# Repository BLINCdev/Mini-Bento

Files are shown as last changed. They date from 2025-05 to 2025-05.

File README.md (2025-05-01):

# Mini Bento Arm
The [Mini Bento Arm](https://blincdev.ca/mini-bento/mini-bento-overview/) is a 3D printable robotic arm designed specifically for education and take home rehabilitation applications. Building off the success of the full-scale [Bento Arm](https://github.com/BLINCdev/Bento-Arm-Hardware) (which has been used extensively as a robotic prosthesis for myoelectric training and research), the 1/3 scale Mini Bento Arm provides many of the same features for a fraction of the cost (and space!). The Dynamixel XL330-M288-T actuators are used in the arm to provide up to 4 movements and include joint feedback that can be used for sensory feedback or machine learning. The arm can be controlled through a computer via our brachI/Oplexus software or directly via the onboard OpenRB-150 controller through an Arduino interface. 

## Build your own Mini Bento Arm
The Mini Bento Arm consists of off-the-shelf X-series Dynamixel actuators and brackets, metric fasteners, and custom 3D printed parts. Instructions for building the arm and setting up the actuators can be found in _'Mini Bento Arm - Assembly Guide.doc'_. The assembly guide will be your main goto document while printing and building the arm and includes references to the other files in the repository:

* __Bill of Materials:__ A detailed list of the off-the-shelf materials and parts required to build the Mini Bento Arm. Note: We have listed the distributors that we have used in the past as a point of reference, but be aware that there are multiple distributor options for each part and that we do not specifically endorse the listed distributors.
* __3D Printing Guide:__ The printing guide includes a list of the 3D prints and print settings (Table 1) and how they relate to the part names in the main Solidworks Assembly.
* __3D Print Files:__ The folder that contains the raw STL files as well as the .THING and .x3g files for 3D printing on a Makerbot Replicator 2. NOTE: The STL files have been adjusted to print with proper tolerances in the PLA material.
* __Solidworks Files:__ The folder that contains the Solidworks part and assembly files. The main assembly file for the entire arm is called 'mini_bento_assembly_rev2.sldasm'. The parts and assemblies were modelled in Solidworks 2016 SP 1. The tolerances on specific parts can be dialed into other printers by changing the PLA_shrink value in 'common_dimensions.txt' to the amount that small holes typically shrink in your printer and then rebuilding/exporting the parts as STL files.
* __STEP Files:__ This folder contains the STEP file for the main assembly and should be importable into most alternate 3D CAD softwares.

## Contributing
You can share your experience, new design, ideas, feature requests, or questions by [contacting us](https://blincdev.ca/contact/).

If you would like to contribute to future official releases of the Mini Bento Arm we recommend contacting us through our wbsite to coordinate with our development team. To get started you will need to [fork this repo](https://help.github.com/articles/using-pull-requests/) and once your modification or enhancement is complete submit a [pull request](https://help.github.com/articles/using-pull-requests/).

## License
The Mini Bento Arm hardware is released under the [Creative Commons BY-SA 4.0](http://creativecommons.org/licenses/by-sa/4.0/) license. A local copy of the license that was forked from [https://github.com/idleberg/Creative-Commons-4.0-Markdown](https://github.com/idleberg/Creative-Commons-4.0-Markdown) is available in the repository. The Mini Bento software is released under the [GNU General Public License v3](https://www.gnu.org/licenses/gpl.html). A local copy is available in the repository.

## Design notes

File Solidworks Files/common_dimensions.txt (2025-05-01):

"PLA_shrink"=0.3mm
"fit_sliding"=0.5mm
"fit_snap"=0.3mm
"fit_tight"=0.2mm
"m2_tap"= 1.75mm + "PLA_shrink"
"m2_thin_wall"= 1.9mm + "PLA_shrink"
"m2_standard"= 2.2mm + "PLA_shrink"
"m2_head"= 3.45mm + "PLA_shrink"
"m2.5_tap"= 2.05 + "PLA_shrink"
"m2.5_standard"= 2.75 + "PLA_shrink"
"m2.5_head"= 5mm + "PLA_shrink"
"m3_tap"= 2.5mm + "PLA_shrink"
"m3_standard"= 3.3mm + "PLA_shrink"
"m3_head"= 6mm + "PLA_shrink"
"connector_width"= 9.35mm
"wire_width"= 3.1mm + "PLA_shrink"

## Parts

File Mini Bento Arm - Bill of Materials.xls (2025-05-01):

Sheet: Mini Bento BOM - QTY1_181224
Mini Bento Arm (PLA Model) - Bill of Materials
QTY: | 1
Date: 18/12/2024
Item | Description | Vendor | Part No. | Website | Req Qty | Cost/Item | Cost | Curr
Dynamixel XL330-M288-T Motor | Dynamixel XL330-M288-T Motor (5V, 0.52 kg*cm) | Robotis US Shop | 902-0163-000 | https://www.robotis.us/dynamixel-xl330-m288-t/ | 3 | $23.90 | $71.70 | USD | 0 in stock (2 week lead time 18/12/2024)
OpenRB-150 Starter Kit | Arduino compatible embedded controller for Dynamixel Actuators Includes: QTY:1 XL330-M288-T | Robotis US Shop | 902-0183-000 | https://www.robotis.us/openrb-150-starter-kit/ | 1 | $45.90 | $45.90 | USD
FPX330-H101 | Hinge Frame and Idler Set for Dynamixel XL330 (4pcs Set) | Robotis US Shop | 903-0302-000 | https://www.robotis.us/fpx330-h101-4pcs-set/ | 1 | $9.80 | $9.80 | USD
FPX330-S102 | Top/Bottom frame for Dynamixel XL330 (4pcs Set) | Robotis US Shop | 903-0300-000 | https://www.robotis.us/fpx330-s102-4pcs-set/ | 1 | $8.70 | $8.70 | USD
PLA Filament (1) | PLA - Black 1.75mm - (0.03 cents/g) | RepRap Warehouse |  | https://www.reprapwarehouse.com/collections/performance-pla/products/performance-pla-by-matter3d-inc | 11 | $0.03 | $0.33 | CAD
PLA Filament (2) | PLA - White 1.75mm - (0.03 cents/g) | RepRap Warehouse |  | https://www.reprapwarehouse.com/collections/performance-pla/products/performance-pla-by-matter3d-inc | 146 | $0.03 | $4.38 | CAD
5V/4A Power Supply | Mean Well AC Adapter, 5V @ 4A | digikey | 1866-2111-ND | https://www.digikey.ca/en/products/detail/mean-well-usa-inc/GST25U05-P1J/7703672 | 1 | $20.59 | $20.59 | CAD
DC Barrel Jack - Female | Cable Assembly 2.1mm ID, 5.5mm OD Jack to Wire Leads Round 1.00' (305.00mm) | digikey | 839-10-03609-ND | https://www.digikey.ca/en/products/detail/tensility-international-corp/10-03609/12090912 | 1 | $9.56 | $9.56 | CAD
Mini breadboard | Solderless Breadboard Terminal Strip (No Frame) 1.75" x 1.38" (44.5mm x 35.1mm), white, Parallax Inc. | digikey | 700-00012-ND | https://www.digikey.ca/en/products/detail/parallax-inc/700-00012/1774444 | 0 | $6.39 | $0.00 | CAD
AAA battery holder | Battery Holder (Open) AAA 3 Cell Wire Leads - 6" (152.4mm) | digikey | 36-2480-ND | https://www.digikey.ca/en/products/detail/keystone-electronics/2480/303825 | 0 | $2.66 | $0.00 | CAD | 0 in stock (18/12/2024)
Slide Switch | SWITCH SLIDE SPDT 3A 30V | digikey | GH36S010001 | https://www.digikey.ca/en/products/detail/apem-inc/GH36S010001/1796125 | 0 | $9.47 | $0.00 | CAD
PSP joystick | Thumbstick, 2 - Axis Analog (Resistive) Output | digikey | 2765 | https://www.digikey.ca/en/products/detail/adafruit-industries-llc/2765/6193582 | 0 | $4.01 | $0.00 | CAD
PSP joystick breakout board | ANALOG MINI THUMBSTICK BREAKOUT | digikey | 3246 | https://www.digikey.ca/en/products/detail/adafruit-industries-llc/3246/6193594 | 0 | $2.25 | $0.00 | CAD
5V Voltager Regulator | Polulu Non-Isolated PoL Module DC DC Converter 1 Output 5V 3.5A 1.3V - 5V Input | polulu | 4012 | https://www.pololu.com/product/4012 | 0 | $7.95 | $0.00 | USD
USB C to USB A cable | UGREEN USB C Cable USB Type C to USB 3.0 (3ft) (for connecting from OpenRB-150 to computer) | amazon.ca | 049-012-NA-BK | https://www.amazon.ca/UGREEN-Charging-Charger-Samsung-A1%EF%BC%883ft%EF%BC%89/dp/B01M679ZM5/r | 1 | $8.96 | $8.96 | CAD
Thumb Joystick | Wishiot PS2 Joystick Axis Sensor Module Game Controller Joystick Breakout Module for Arduino（Pack of 10） | amazon.ca | B094HRM72Z | https://www.amazon.ca/Wishiot-Joystick-Controller-Breakout-Arduino%EF%BC%88Pack/dp/B089VXPHDH/ | 1 | $21.99 | $21.99 | CAD
Breadboard Jumper Wires | Aypzuke 10cm 240pcs Breadboard Jumper Wires Cable Kit Male to Female | amazon.ca | B0BTT31CBC | https://www.amazon.ca/EDGELEC-Breadboard-Optional-Assorted-Multicolored/dp/B07GD1XFWV/?th=1 | 1 | $13.99 | $13.99 | CAD
2" C-Clamp | Irwin Tools 225102ZR C-CLAMP 2" | amazon.ca | 225102ZR | https://www.amazon.ca/Bessey-CM20-2-Inch-1-Inch-Malleable/dp/B0006694H8/?th=1 | 0 | $3.99 | $0.00 | CAD
Adhesive Grip Tape | Razer Universal Grip Tape for Gaming Peripherals and Devices | amazon.ca | ‎RC21-01670100-R3M1 | https://www.amazon.ca/Razer-Universal-Gaming-Peripherals-Devices/dp/B091DD8FTH/ | 1 | $17.67 | $17.67 | CAD
Plastic Suction Cups (20mm diameter) | PATIKIL Suction Cups 20mm/0.8 Inch (Pack of 10) | amazon.ca | pta240619tt001609eu | https://www.amazon.ca/PATIKIL-Suction-Bathroom-Organization-Decoration/dp/B0DCP3TNWZ?th=1 | 0 | $7.99 | $0.00 | CAD
AAA Batteries | Energizer Rechargeable AAA Batteries, Recharge Power Plus Triple A Battery Pre-Charged, 4 Count | amazon.ca | EVENH12BP4 | https://www.amazon.ca/Energizer-Rechargeable-Batteries-Pre-Charged-Recharge/dp/B000BESLQK/ | 0 | $11.18 | $0.00 | CAD
 |  |  |  |  |  | *TOTAL COST: | $273.66
*NOTE: Estimated costs do not include taxes, shipping charges, or duties

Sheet: Mini Bento BOM - QTY1_300425
Mini Bento Arm (PLA Model) - Bill of Materials
QTY: | 1
Date: 30/04/2025
Item | Description | Vendor | Part No. | Website | Req Qty | Cost/Item | Cost | Curr
Dynamixel XL330-M288-T Motor | Dynamixel XL330-M288-T Motor (5V, 0.52 kg*cm) | Robotis US Shop | 902-0163-000 | https://www.robotis.us/dynamixel-xl330-m288-t/ | 3 | $26.29 | $78.87 | USD
OpenRB-150 Starter Kit | Arduino compatible embedded controller for Dynamixel Actuators Includes: QTY:1 XL330-M288-T | Robotis US Shop | 902-0183-000 | https://www.robotis.us/openrb-150-starter-kit/ | 1 | $50.49 | $50.49 | USD
FPX330-H101 | Hinge Frame and Idler Set for Dynamixel XL330 (4pcs Set) | Robotis US Shop | 903-0302-000 | https://www.robotis.us/fpx330-h101-4pcs-set/ | 1 | $10.78 | $10.78 | USD
FPX330-S102 | Top/Bottom frame for Dynamixel XL330 (4pcs Set) | Robotis US Shop | 903-0300-000 | https://www.robotis.us/fpx330-s102-4pcs-set/ | 1 | $10.78 | $10.78 | USD
PLA Filament (1) | PLA - Black 1.75mm - (0.03 cents/g) | RepRap Warehouse |  | https://www.reprapwarehouse.com/collections/performance-pla/products/performance-pla-by-matter3d-inc | 1 | $34.99 | $34.99 | CAD
PLA Filament (2) | PLA - White 1.75mm - (0.03 cents/g) | RepRap Warehouse |  | https://www.reprapwarehouse.com/collections/performance-pla/products/performance-pla-by-matter3d-inc | 1 | $34.99 | $34.99 | CAD
5V/4A Power Supply | Mean Well AC Adapter, 5V @ 4A | digikey | 1866-2111-ND | https://www.digikey.ca/en/products/detail/mean-well-usa-inc/GST25U05-P1J/7703672 | 1 | $15.96 | $15.96 | CAD
DC Barrel Jack - Female | Cable Assembly 2.1mm ID, 5.5mm OD Jack to Wire Leads Round 1.00' (305.00mm) | digikey | 839-10-03609-ND | https://www.digikey.ca/en/products/detail/tensility-international-corp/10-03609/12090912 | 1 | $10.87 | $10.87 | CAD
Mini breadboard (Optional) | Solderless Breadboard Terminal Strip (No Frame) 1.75" x 1.38" (44.5mm x 35.1mm), white, Parallax Inc. | digikey | 700-00012-ND | https://www.digikey.ca/en/products/detail/parallax-inc/700-00012/1774444 | 0 | $3.99 | $0.00 | CAD
PSP joystick (Optional) | Thumbstick, 2 - Axis Analog (Resistive) Output | digikey | 2765 | https://www.digikey.ca/en/products/detail/adafruit-industries-llc/2765/6193582 | 0 | $2.50 | $0.00 | CAD
PSP joystick breakout board (Optional) | ANALOG MINI THUMBSTICK BREAKOUT | digikey | 3246 | https://www.digikey.ca/en/products/detail/adafruit-industries-llc/3246/6193594 | 0 | $1.50 | $0.00 | CAD
USB C to USB A cable | UGREEN USB C Cable USB Type C to USB 3.0 (3ft) (for connecting from OpenRB-150 to computer) | amazon.ca | 049-012-NA-BK | https://www.amazon.ca/UGREEN-Charging-Charger-Samsung-A1%EF%BC%883ft%EF%BC%89/dp/B01M679ZM5/r | 1 | $9.99 | $9.99 | CAD
Thumb Joystick | Wishiot PS2 Joystick Axis Sensor Module Game Controller Joystick Breakout Module for Arduino（Pack of 10） | amazon.ca | B094HRM72Z | https://www.amazon.ca/Wishiot-Joystick-Controller-Breakout-Arduino%EF%BC%88Pack/dp/B089VXPHDH/ | 1 | $21.99 | $21.99 | CAD
Breadboard Jumper Wires | Aypzuke 10cm 240pcs Breadboard Jumper Wires Cable Kit Male to Female | amazon.ca | B0BTT31CBC | https://www.amazon.ca/EDGELEC-Breadboard-Optional-Assorted-Multicolored/dp/B07GD1XFWV/?th=1 | 1 | $13.99 | $13.99 | CAD
Adhesive Grip Tape | Razer Universal Grip Tape for Gaming Peripherals and Devices | amazon.ca | ‎RC21-01670100-R3M1 | https://www.amazon.ca/Razer-Universal-Gaming-Peripherals-Devices/dp/B091DD8FTH/ | 1 | $14.99 | $14.99 | CAD
2" C-Clamp (Optional) | BESSEY TOOLS CM20 2", Drop Forged, C-Clamp | amazon.ca | CM20 | https://www.amazon.ca/Bessey-CM20-2-Inch-1-Inch-Malleable/dp/B0006694H8/?th=1 | 0 | $3.99 | $0.00 | CAD
Plastic Suction Cups (Optional) | PATIKIL Suction Cups 20mm/0.8 Inch (Pack of 10) | amazon.ca | pta240619tt001609eu | https://www.amazon.ca/PATIKIL-Suction-Bathroom-Organization-Decoration/dp/B0DCP3TNWZ?th=1 | 0 | $7.99 | $0.00 | CAD
 |  |  |  |  |  | *TOTAL COST: | $367.55 | CAD
*NOTE: Estimated costs do not include taxes, shipping charges, or duties

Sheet: Fasteners
 | Total Screws Required
 | Fastener Type | Pitch(mm) | Head Type | Length | Required | Available* | Left Over
 | M2.6 | 0.8 | PHILLIPS | 6 | 3 | 8 | 5 | * These are the screws available if you purchase QTY:4 XL330-M288-T, QTY:1 FPX330-H101, and QTY:1 FPX330-S102
 | M2 | 0.6 | PHILLIPS | 4 | 48 | 56 | 8
 | M2 | 0.6 | PHILLIPS | 6 | 10 | 24 | 14
 | M2 | 0.6 | PHILLIPS | 8 | 34 | 60 | 26
 | M2 | 0.4 | PHILLIPS | 4 | 8 | 40 | 32
Item | Fastener Type | Pitch (mm) | Head Type | Length (mm) | QTY
stand_base to upper_stand (front) | M2 | 0.6 | PHILLIPS | 6 | 2
stand_base to upper_stand (back) | M2 | 0.6 | PHILLIPS | 8 | 2
stand corner brackets | M2 | 0.6 | PHILLIPS | 8 | 2
electronics_plate to stand_base | M2 | 0.6 | PHILLIPS | 4 | 6
Cable Plate (2 holes) | M2 | 0.6 | PHILLIPS | 4 | 2
Cable Plate (4 holes) | M2 | 0.6 | PHILLIPS | 4 | 4
Thumb joysticks (QTY:1) | M2 | 0.6 | PHILLIPS | 8 | 6
OpenRB-150 | M2 | 0.6 | PHILLIPS | 6 | 0
OpenRB-150 Standoff (Top) | M2 | 0.6 | PHILLIPS | 6 | 4
OpenRB-150 Standoff (Bottom) | M2 | 0.6 | PHILLIPS | 6 | 4
shoulder adapter to stand | M2 | 0.6 | PHILLIPS | 8 | 4
shoulder adapter to shoulder motor | M2 | 0.6 | PHILLIPS | 8 | 4
shoulder horn to XL-330_side_bracket | M2 | 0.6 | PHILLIPS | 4 | 4
XL-330_side_bracket to elbow motor | M2 | 0.6 | PHILLIPS | 8 | 4
elbow motor to flex bracket | M2 | 0.6 | PHILLIPS | 4 | 8
flex bracket idler | M2.6 | 0.8 | PHILLIPS | 6 | 1
flex bracket to bottom bracket (wrist) | M2 | 0.4 | PHILLIPS | 4 | 4
bottom bracket (wrist) to wrist motor | M2 | 0.6 | PHILLIPS | 8 | 4
wrist motor to flex bracket | M2 | 0.6 | PHILLIPS | 4 | 8
flex bracket idler | M2.6 | 0.8 | PHILLIPS | 6 | 1
flex bracket to bottom bracket (gripper) | M2 | 0.4 | PHILLIPS | 4 | 4
bottom bracket (gripper) to gripper motor | M2 | 0.6 | PHILLIPS | 8 | 4
gripper motor to flex bracket | M2 | 0.6 | PHILLIPS | 4 | 8
flex bracket idler | M2.6 | 0.8 | PHILLIPS | 6 | 1
fixed_plate to chopsticks_side_bracket | M2 | 0.6 | PHILLIPS | 4 | 4
chopsticks_side_bracket to gripper motor | M2 | 0.6 | PHILLIPS | 8 | 4
moving plate to flex bracket | M2 | 0.6 | PHILLIPS | 4 | 4

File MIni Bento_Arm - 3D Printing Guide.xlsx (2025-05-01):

Bento Arm V2 3D printed Part List
Note: Part mass is for QTY:1 of a given part
Table 1 - Individual Parts List
Part Name | Part Type | Required QTY | Print Settings | Print Time (min) | Print mass (g) | Part mass (g) | Standard Edition Colors | Classic Bento Edition Colors
electronics_plate_rev2 | Arm - 3D Printed | 1 | Bento_endo_raft | 72 | 35.4 | 21.3 | white
stand_base_rev2 | Arm - 3D Printed | 1 | Bento_endo_raft | 126 | 41.7 | 31.3 | white
upper_stand_rev2 | Arm - 3D Printed | 1 | Bento_endo_raft | 150 | 43.4 | 35.4 | white
corner_bracket_rev2 | Arm - 3D Printed | 2 | Bento_endo_raft | 33 | 12.8 | 8 | white |  | 4g/part
shoulder_adapter_rev2 | Arm - 3D Printed | 1 | Bento_endo_noraft | 22 | 4.2 | 4.2 | black
XL-330_side_bracket_rev2 | Arm - 3D Printed | 1 | Bento_endo_noraft | 25 | 2.8 | 2.8 | black
chopsticks_side_bracket_rev2 | Arm - 3D Printed | 1 | Bento_endo_noraft | 22 | 3.9 | 3.9 | black
chopsticks_fixed_plate_rev2 | Arm - 3D Printed | 1 | Bento_endo_noraft | 17 | 3.6 | 3.6 | white
chopsticks_flex_bracket_rev2 | Arm - 3D Printed | 1 | Bento_endo_noraft | 17 | 3.2 | 3.2 | white
chopsticks_moving_plate_rev2 | Arm - 3D Printed | 1 | Bento_endo_noraft | 17 | 3 | 3 | white
OpenRB_150_standoff_rev2 | Arm - 3D Printed | 2 | Bento_endo_noraft | 10 | 1.4 | 1.4 | white |  | 0.7g/part
cable_plate_4holes_rev2 | Arm - 3D Printed | 1 | standard_noraft | 5 | 1 | 1 | white
cable_plate_2holes_rev2 | Arm - 3D Printed | 1 | standard_noraft | 3 | 0.4 | 0.4 | white
XL-330 | Arm - Purchased | 1 |  |  |  | 18.3
XL-330_flex_FPX330-H101 | Arm - Purchased | 2 |  |  |  | 4.1
XL-330_bottom_FPX330-S102 | Arm - Purchased | 2 |  |  |  | 1.7
XL-330 cables (180mm) | Arm - Purchased | 4 |  |  |  | 3.4
Thumb Joystick | Arm - Purchased | 1 |  |  |  | 10.7
OpenRB-150 | Arm - Purchased | 1 |  |  |  | 18
Mini Breadboard | Arm - Purchased | 1 |  |  |  | 13.5
Armshell parts | Armshell parts |  | standard_noraft | TBD | TBD | TBD |  | translucent blue
Total mass of arm below elbow: | 68.7
Total mass of arm below wrist: | 41.2
Total mass of white PLA | 145.9
Total mass of black PLA | 10.9
Total print time (hours) | 8.65

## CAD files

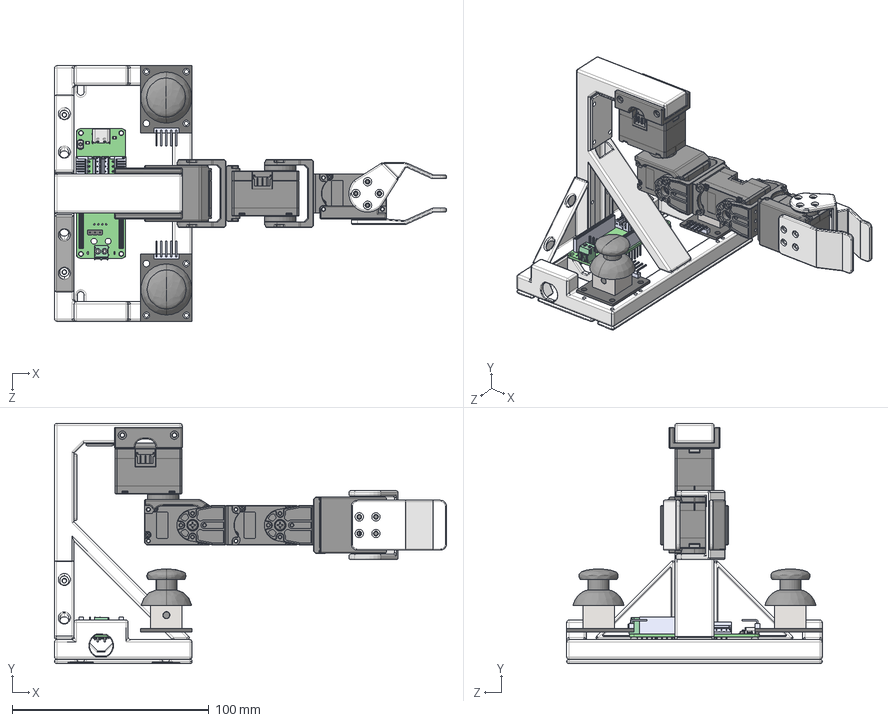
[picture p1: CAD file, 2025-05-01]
Step Files/mini_bento_assembly_rev2.STEP
199.4 x 122.2 x 130.0 mm
electronics_plate_rev2
stand_base_rev2
upper_stand_rev2
corner_bracket_rev2 x 2
shoulder_adapter_rev2
XL-330 x 4
OpenRB_150_simplified
thumb_joystick_pcb_rev2 x 2
thumb_joystick_knob_rev2 x 2
OpenRB_150_standoff_rev2 x 2
cable_plate_4holes_rev2
cable_plate_2holes_rev2
XL-330_side_bracket_rev2
XL-330_idle_bearing x 3
XL-330_idle_horn x 3
XL-330_flex_FPX330-H101 x 2
XL-330_bottom_FPX330-S102 x 2
chopsticks_side_bracket_rev2
chopsticks_fixed_plate_rev2
chopsticks_flex_bracket_rev2
chopsticks_moving_plate_rev2

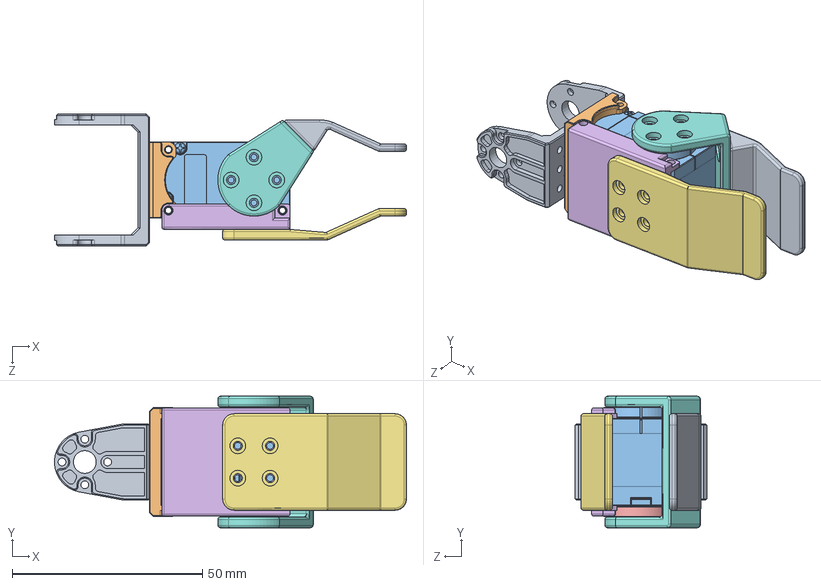
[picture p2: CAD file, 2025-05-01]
Solidworks Files/hand_assembly_rev2.SLDASM
92.6 x 34.6 x 34.6 mm
XL-330_flex_FPX330-H101
XL-330_bottom_FPX330-S102
XL-330
XL-330_idle_bearing
XL-330_idle_horn
chopsticks_side_bracket_rev2
chopsticks_fixed_plate_rev2
chopsticks_flex_bracket_rev2
chopsticks_moving_plate_rev2

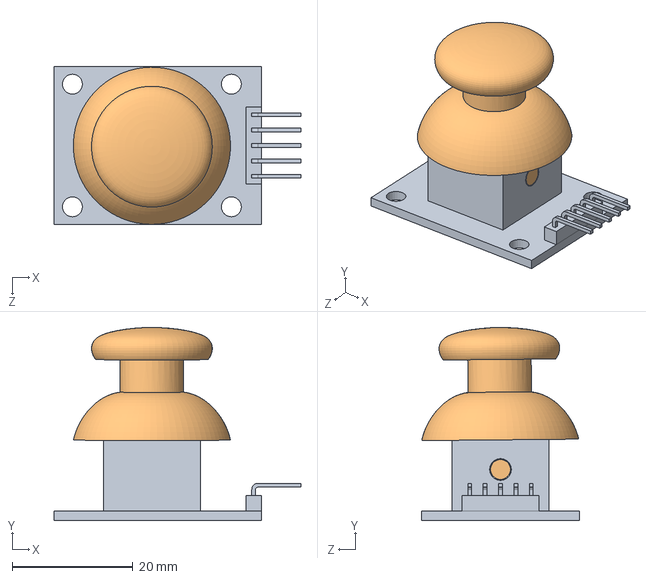
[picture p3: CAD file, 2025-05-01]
Solidworks Files/thumb_joystick_assembly_rev2.SLDASM
40.9 x 31.9 x 26.2 mm
thumb_joystick_pcb_rev2
thumb_joystick_knob_rev2

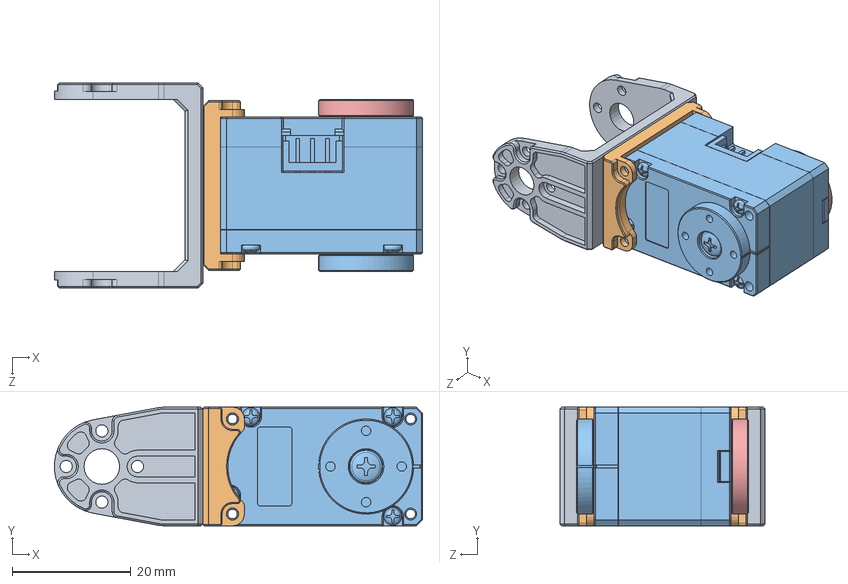
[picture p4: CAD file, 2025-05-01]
Solidworks Files/wrist_assembly_rev2.SLDASM
62.0 x 20.0 x 34.6 mm
XL-330_flex_FPX330-H101
XL-330_bottom_FPX330-S102
XL-330
XL-330_idle_bearing
XL-330_idle_horn

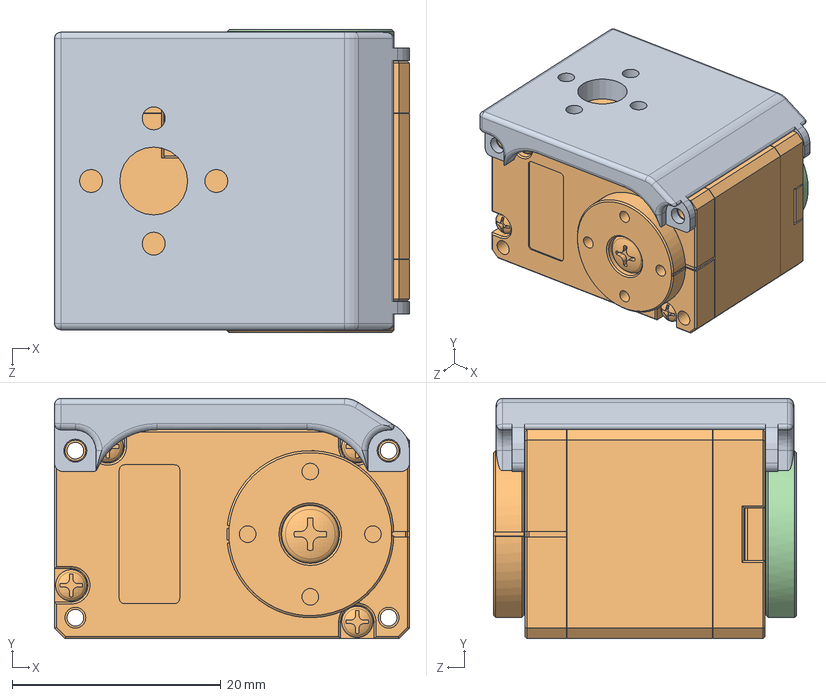
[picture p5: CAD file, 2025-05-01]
Solidworks Files/elbow_assembly_rev2.SLDASM
34.0 x 23.0 x 29.0 mm
XL-330_side_bracket_rev2
XL-330
XL-330_idle_bearing
XL-330_idle_horn

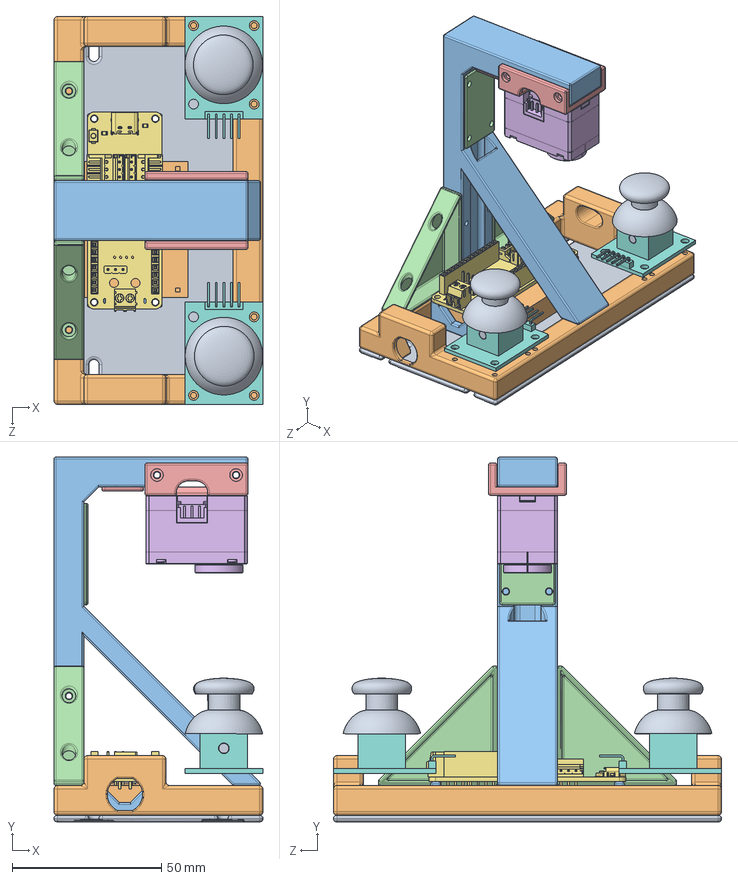
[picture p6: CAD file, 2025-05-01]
Solidworks Files/mini_stand_assembly_rev2.SLDASM
70.0 x 122.2 x 130.0 mm
electronics_plate_rev2
stand_base_rev2
upper_stand_rev2
corner_bracket_rev2 x 2
shoulder_adapter_rev2
XL-330
OpenRB_150_simplified
thumb_joystick_pcb_rev2 x 2
thumb_joystick_knob_rev2 x 2
mini_breadboard_rev2
OpenRB_150_standoff_rev2 x 2
cable_plate_4holes_rev2
cable_plate_2holes_rev2

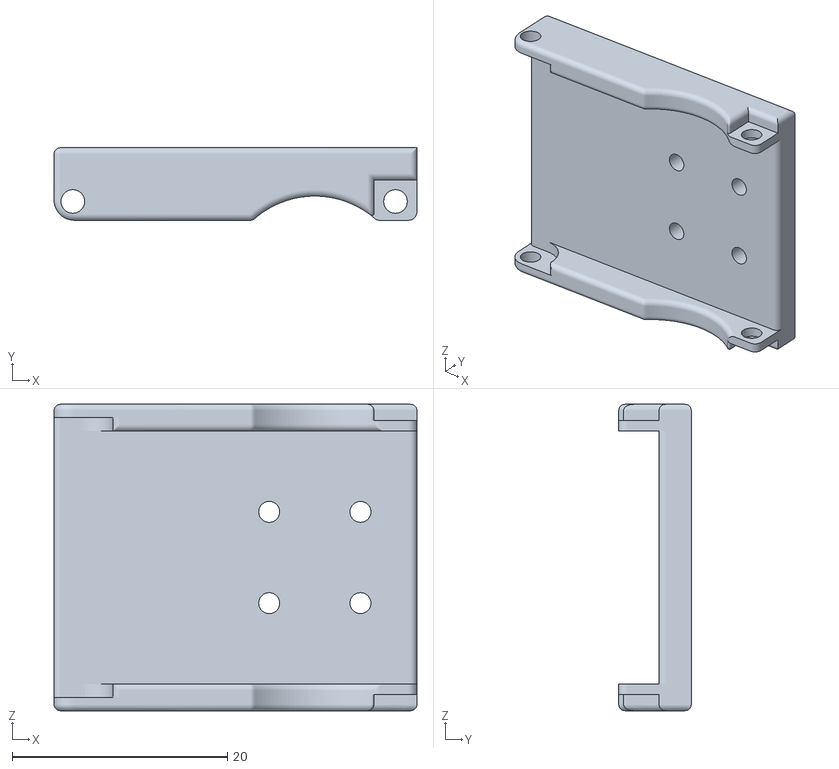
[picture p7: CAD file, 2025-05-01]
3D Print Files/chopsticks_side_bracket_rev2f.STL
33.8 x 6.75 x 28.5

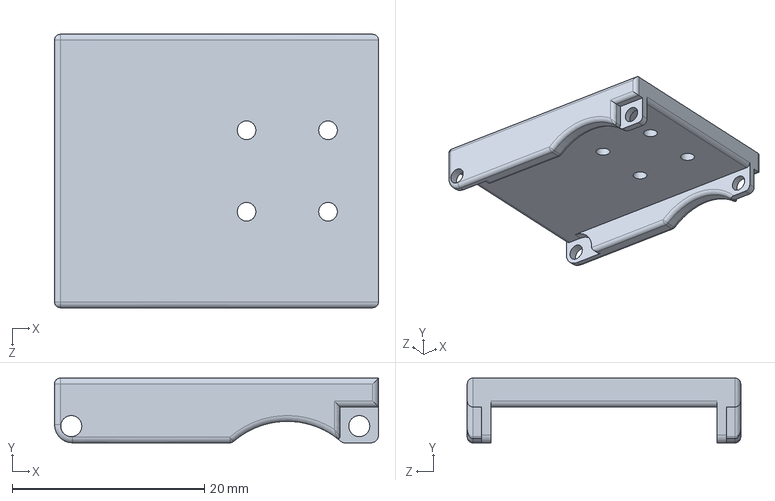
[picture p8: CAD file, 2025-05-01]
Solidworks Files/chopsticks_side_bracket_rev2.SLDPRT
33.8 x 6.75 x 28.5 mm

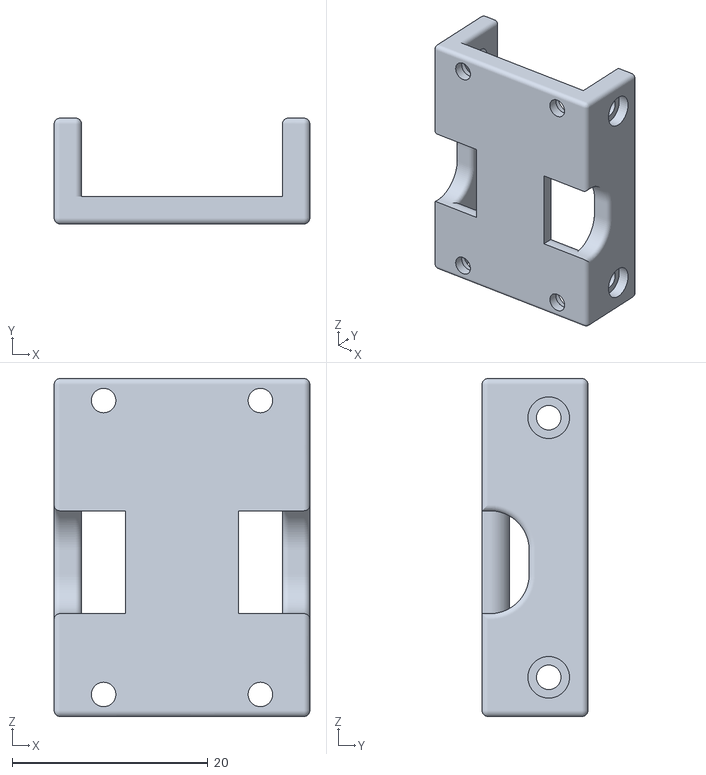
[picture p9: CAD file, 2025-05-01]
3D Print Files/shoulder_adapter_rev2b.STL
26.1 x 10.8 x 34.5

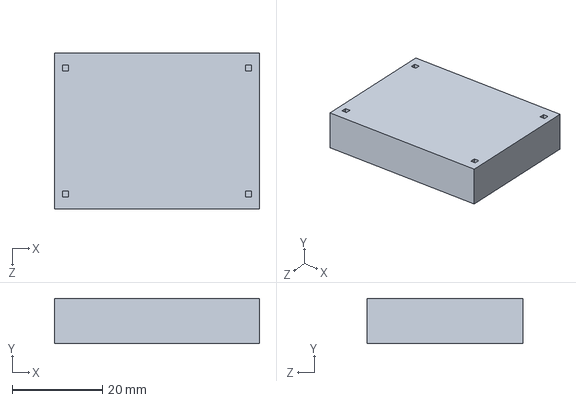
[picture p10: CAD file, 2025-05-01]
Solidworks Files/mini_breadboard_rev2.SLDPRT
45.5 x 10.0 x 34.7 mm

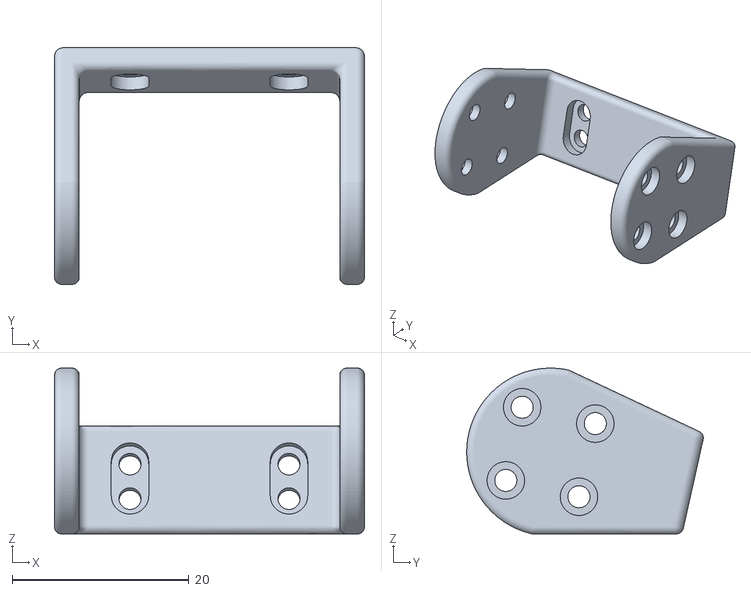
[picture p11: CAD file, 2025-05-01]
3D Print Files/chopsticks_flex_bracket_rev2b.STL
35.1 x 26.8 x 18.8

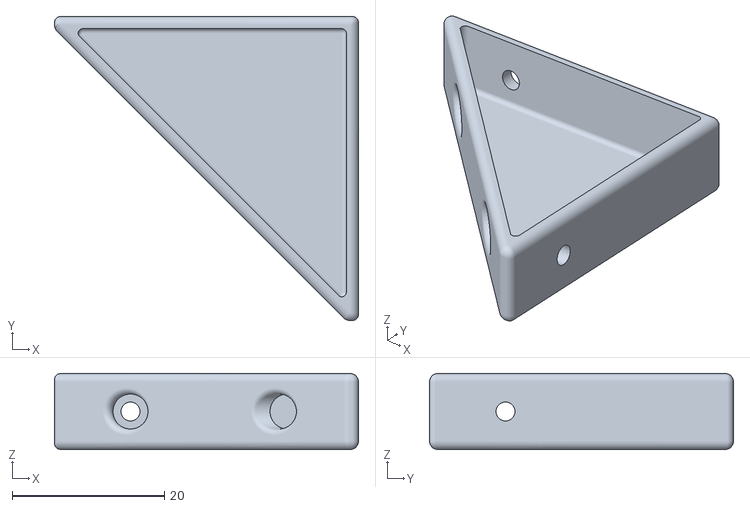
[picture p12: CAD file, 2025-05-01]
3D Print Files/corner_bracket_rev2b.STL
40.0 x 40.0 x 10.0

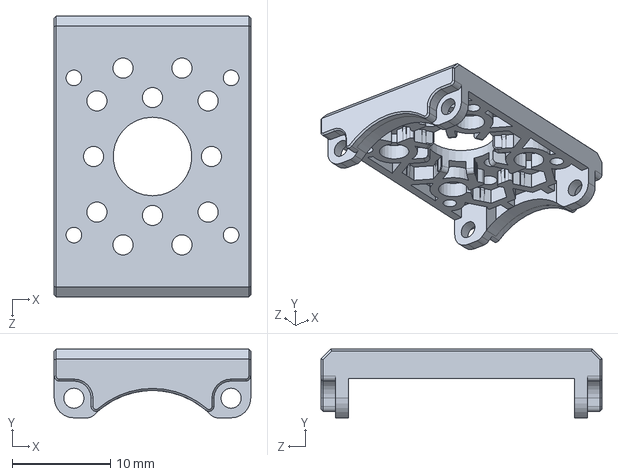
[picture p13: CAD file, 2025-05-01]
Solidworks Files/XL-330_bottom_FPX330-S102.SLDPRT
20.0 x 7.00 x 28.6 mm

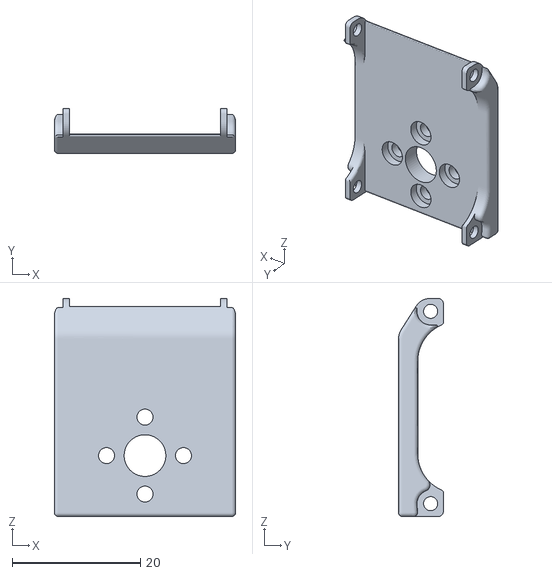
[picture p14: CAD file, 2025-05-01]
3D Print Files/XL-330_side_bracket_rev2b.STL
28.3 x 7.00 x 34.0

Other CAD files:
Solidworks Files/electronics_plate_rev2.SLDPRT
3D Print Files/bunny_ear_rev1.STL
Solidworks Files/OpenRB_150_standoff_rev2.SLDPRT
3D Print Files/electronics_plate_rev2b.STL
3D Print Files/OpenRB_150_standoff_rev2.STL
3D Print Files/cable_plate_2holes_rev2.STL
3D Print Files/cable_plate_4holes_rev2.STL
3D Print Files/chopsticks_fixed_plate_rev2.STL
3D Print Files/chopsticks_moving_plate_rev2b.STL
3D Print Files/stand_base_rev2b.STL
3D Print Files/upper_stand_rev2b.STL
Solidworks Files/OpenRB_150_simplified.SLDPRT
Solidworks Files/XL-330.SLDPRT
Solidworks Files/XL-330_flex_FPX330-H101.SLDPRT
Solidworks Files/XL-330_idle_bearing.SLDPRT
Solidworks Files/XL-330_idle_horn.SLDPRT
Solidworks Files/XL-330_side_bracket_rev2.SLDPRT
Solidworks Files/cable_plate_2holes_rev2.SLDPRT
Solidworks Files/cable_plate_4holes_rev2.SLDPRT
Solidworks Files/chopsticks_fixed_plate_rev2.SLDPRT
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

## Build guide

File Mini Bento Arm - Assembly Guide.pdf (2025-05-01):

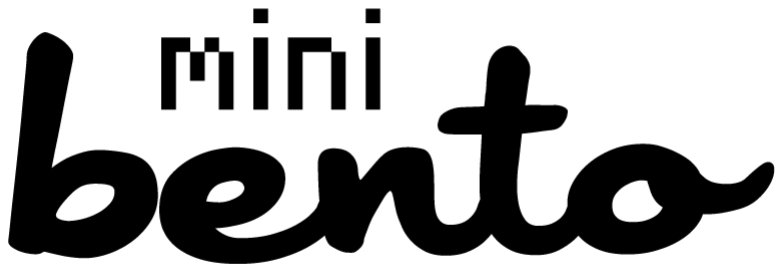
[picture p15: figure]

# Assembly Manual

Michael R. Dawson

Apr 30th, 2025

## Table of Contents

## Mini Bento Arm Assembly Manual

### 1.1 Introduction

This guide will help you from start to finish with creating a new Mini Bento Arm including acquiring purchased parts, 3D printing custom parts, setting up the servos so that they can be controlled through some of the available software interfaces, and assembly of all parts.

### 1.2 Bill of materials

Please see Mini_Bento_BOM.xls for a full bill of materials for building a single Bento Arm. The bill of materials can be used to help find the parts for each of the assembly steps.

The following tools/materials are required, but not included in the bill of materials:
- RepRap 3D printer capable of printing PLA
- Precision screwdrivers (#1 Phillips and 3/32” Flathead)
- Wire cutters
- Wire strippers
- Needle nose pliers
- Gel super glue
- Label maker

Note: We have listed the distributors that we have used in the past as a point of reference, but be aware that there are multiple distributor options for each part and that we do not endorse the listed distributors.

### 1.3 3D Printed Parts

Required Tools: Makerbot Replicator 2 3D printer or similar
Required Materials: 140g of PLA filament (130g white PLA, 10g black PLA) Estimated print time: ~9 hours

In addition to the off-the-shelf parts specified in the bill of materials, 11 additional parts need to be 3D printed for the Mini Bento Arm. In order to minimize post-processing all parts have been designed to be printed without supports in a specific orientation. The STL files for each part are located in the “3D Print Files” folder. We recommend making the following print settings into presets in your slicer to make it easier to select the recommended settings for a given part.

1. Bento_endo_raft
a. Layer height: 0.2mm
b. Infill pattern: linear
c. Infill density: 50%
d. raft margin: 6mm or greater
2. Bento_endo_noraft
a. Layer height: 0.2mm
b. Infill pattern: linear
c. Infill density: 50%
d. raft: none

NOTE1: It is very important to use the recommended print orientation since we have tried as much as possible to align the print grain in the optimal orientation for the loading of the part. You can check the orientation for each part in the screenshots below or you can download and installer Makerware (https://www.dropbox.com/s/idy25zzufzkoncr/MakerWare_Bundle_of_Awesome_2.4.1.24_x64.exe?dl=0) (Version 2.4.1.24) and open the .thing files.

NOTE2: If you have a heated bed on your 3D printer, then you can use the “Bento_endo_noraft” settings for all parts listed below to avoid the extra step of needing to remove the rafts. If you do not have a heated bed on your printer then you should use the “Bento_endo_raft” settings on the indicated parts to avoid the issue where the corners curl up during the print. If you are finding that the corners are curling up even with the raft then you can also add “bunny_ear_rev1.STL” to the corners of your prints to help extend the raft around the corners which can also help avoid the curling issue:

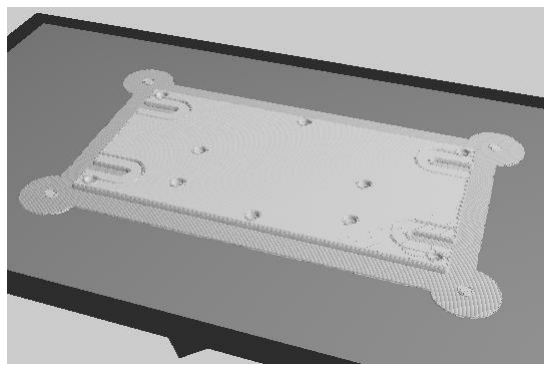
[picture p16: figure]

NOTE3: If you have a Makerbot Replicator 2, you can skip the slicing step and 3D print all the .x3g files that we have presliced for you. To save even more time, the items with material properties “Bento_endo_noraft” (i.e. parts 5,6,7, and parts 8-11), can be printed altogether in a given PLA color using “parts_noraft_white.x3g” and “parts_noraft_black.x3g”.

The recommended materials, print settings, and print orientations for each part are outlined below and also detailed in “Mini Bento Arm_V2_3Dprinting_guide.xlsx”. You can use this information to slice each part in the slicer for your 3D printer and then proceed to print the parts.

1. electronics_plate_rev2
a. material: makerbot true white PLA or similar
b. settings: bento_endo_raft
c. mass: 35g
d. time: 72 min
2. stand_base_rev2
a. material: makerbot true white PLA or similar
b. settings: bento_endo_raft
c. mass: 42g
d. time: 126 min
3. upper_stand_rev2
a. material: makerbot true white PLA or similar
b. settings: bento_endo_raft
c. mass: 43.4g
d. time: 150 min
4. corner_bracket_rev2 (QTY:2)
a. material: makerbot true white PLA or similar
b. settings: bento_endo_raft
c. mass: 4g per part (8g total)
d. time: 33 min (for both parts)
5. shoulder_adapter_rev2
a. material: makerbot true black PLA or similar
b. settings: bento_endo_noraft
c. mass: 4g
d. time: 22min

6. XL-330_side_bracket_rev2
a. material: makerbot true black PLA or similar
b. settings: bento_endo_noraft
c. mass: 3g
d. time: 25 min
7. chopsticks_side_bracket_rev2
a. material: makerbot true black PLA or similar
b. settings: bento_endo_noraft
c. mass: 3g
d. time: 22min
8. chopsticks_fixed_plate_rev2
a. material: makerbot true white PLA or similar
b. settings: bento_endo_noraft
c. mass: 4g
d. time: 17 min
9. chopsticks_flex_bracket_rev2
a. material: makerbot true white PLA or similar
b. settings: bento_endo_noraft
c. mass: 3g
d. time: 17 min
10. chopsticks_moving_plate_rev2
a. material: makerbot true white PLA or similar
b. settings: bento_endo_noraft
c. mass: 3g
d. time: 17 min
11. OpenRB_150_standoff_rev2 (QTY:2)
a. material: makerbot true white PLA or similar
b. settings: bento_endo_noraft
c. mass: 1g
d. time: 10 min

Optional Parts: Also, feel free to also print QTY:1 of “cable_plate_4holes_rev2” and “cable_plate_2holes_rev2”. These parts are used to help clean-up the wiring that runs from the actuators to the OpenRB-150 controller.

### 1.4 Dynamixel Servo Programming

Required Tools: Computer with Windows 10 or higher, OpenRB-150 (https://emanual.robotis.com/docs/en/parts/controller/openrb-150/) or similar, 5V/4A power supply, DC Barrel Jack (female), USB C to USB A cable
Estimated time: 0.5 hours

Table 1 – Servo settings and Joint Limits
Arm Function | Servo Type | Servo ID | Baud Rate | Return Delay Time | Max Position Limit | Min Position Limit | PWM Limit
Shoulder Rotation | XL330-M288-T | 1 | 3 (1 Mbps) | 10 (20usec) | 3073 | 1023 | 354
Elbow Flexion | XL330-M288-T | 2 | 3 (1 Mbps) | 10 (20usec) | 2700 | 1150 | 443
Wrist Flexion | XL330-M288-T | 4 | 3 (1 Mbps) | 10 (20usec) | 3248 | 848 | 354
Chopsticks Gripper | XL330-M288-T | 5 | 3 (1 Mbps) | 10 (20usec) | 2658 | 1650 | 354
1. Label servos ID1, ID2, ID4, and ID5 according to the above Table 1 with a label maker

NOTE1: Be sure to skip ID3 since it is reserved for wrist rotation which is not present in this version of the Mini Bento Arm. This will allow all the servos to match up with the naming convention in the full scale Bento Arm.

2. Ensure the power source jumper on the OpenRB-150 controller is set to VIN (DXL). When in this mode the board and connected servomotors will be powered via the green terminal block.

3. Connect the DC Barrel Jack (female) to the green terminal block on the OpenRB-150 making sure that the red wire goes into the side labelled “+” and the black wire goes into the side labelled “-“. Once the wires are in place, use a screw driver to tighten the terminal blocks until the wires are secure.

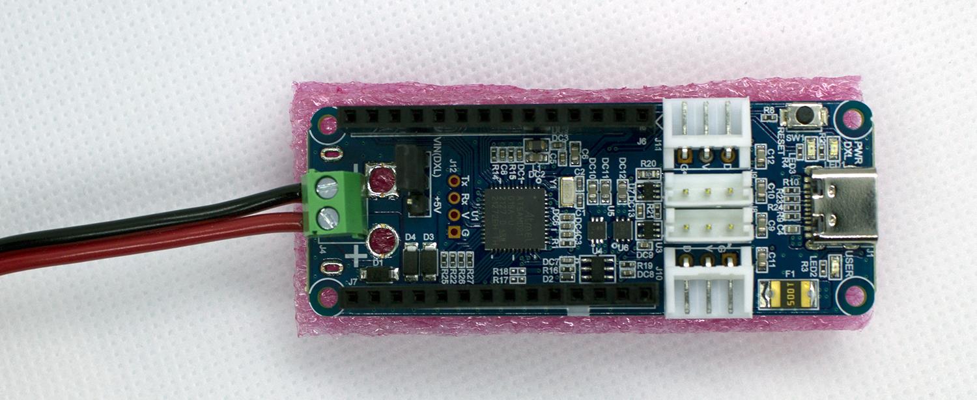
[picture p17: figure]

4. Install the Arduino IDE and set it up to work with the OpenRB-150
a. Download the legacy version of the Arduino IDE 1.8.19 (https://downloads.arduino.cc/arduino-1.8.19-windows.exe) from the Arduino website and double click on “arduino-1.8.19-windows.exe” to install it.
i. NOTE1: The newer versions of the Arduino IDE may also work, but we have not had a chance to test them yet.

b. Open the Arduino IDE and go “file > preferences”. Copy the following address into the “Additional Boards Manager URLs” textbox:

https://raw.githubusercontent.com/ROBOTIS-GIT/OpenRB-150/master/package_openrb_index.json

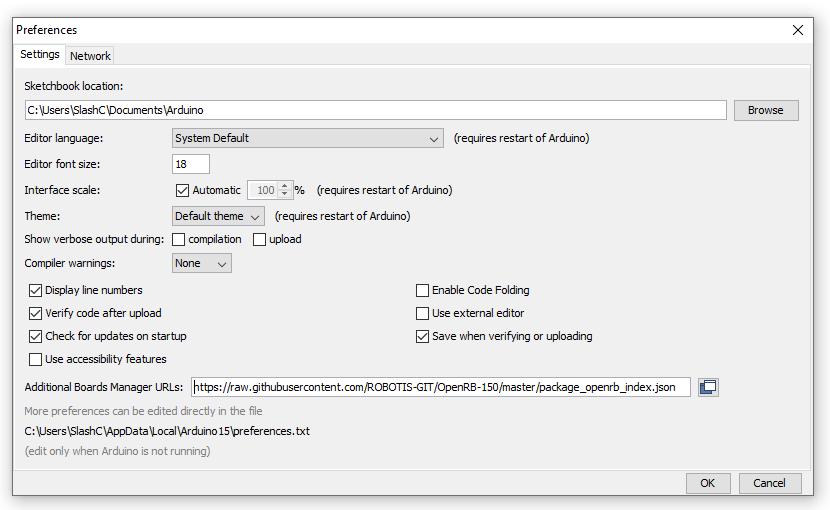
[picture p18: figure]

c. Install the Arduino SAMD board manager by going “tools > board > boards manager”. Search for “Arduino SAMD” and install the latest version.
d. Install the OpenRB-150 board manager by going “tools > board > board manager”. Search for “OpenRB” and install the latest version.

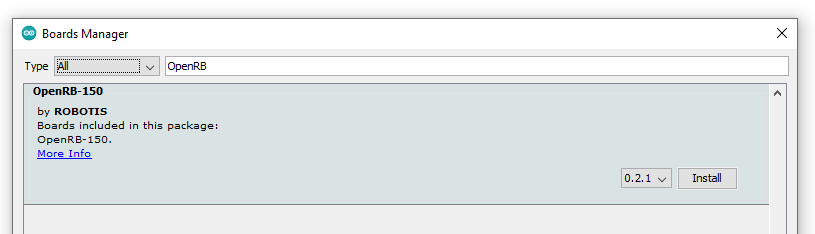
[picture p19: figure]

e. Install the Dynamixel2Arduino library by going “sketch > include library > manage libraries”. Search for “Dynamixel2Arduino” and install the latest version.
f. Install the DynamixelShield library by going “sketch > include library > manage libraries”. Search for “DynamixelShield” and install the latest version.
5. Power on the OpenRB-150 by plugging the 5V/4A power supply into a surge protector or wall outlet and connecting the barrel plug (male) of the power supply to the DC Barrel Jack (female). The green LED on the OpenRB-150 should illuminate indicating that the board has power. A few seconds later the red LED on the OpenRB-150 should also turn on indicating that the Dynamixel bus has initialized and is also now sending power to any connected Dynamixel servos.
6. Connect the OpenRB-150 to the computer using the USB C to USB A cable. If this is the first time you have connected the device Windows may give some notifications that a new device is being setup.
7. Upload the “usb_to_dynamixel” (https://github.com/ROBOTIS-GIT/OpenRB-150/blob/master/libraries/OpenRB-150/examples/usb_to_dynamixel/usb_to_dynamixel.ino) sketch in the Arduino IDE
a. Go “tools > board > OpenRB-150” and select “OpenRB-150”
b. Go “tools > port” and select the option that has “(OpenRB-150)” next to it.
c. Go “file > examples > OpenRB-150” and select the “usb_to_dynamixel” sketch. A new window should open in the Arduino IDE that is titled “usb_to_dynamixel”
d. Click “upload” in the “usb_to_dynamixel” sketch to upload the sketch to the OpenRB-150
8. If it is not already installed on your computer, install the Visual C++ 2015-2019 Distributable (x86) from the following link: https://www.dropbox.com/s/3e5horhq73hm677/VC_redist.x86.exe?dl=0
9. Download and install the latest version of the “Dynamixel Wizard 2.0” Software: http://en.robotis.com/service/downloadpage.php?ca_id=10

10. Once the software is installed, open the Dynamixel Wizard 2.0 and click the “Options” button. Make sure the following items are selected:
a. Select the protocol to scan: Protocol 2.0
b. Select the port to scan: Select the one labelled “USB Serial Device” (should be the same as step 7b)
c. Select the baudrate to scan: 57600 bps and 1000000 bps. These are the most common baud rates that the servos are set to by default
d. Click the “OK” button to save these options.
11. Typically the servos are initialized by default with ID=1. Since all Dynamixel servos on the bus need to have unique ID numbers you will need to repeat the following steps for each servo once when connecting to them for the first time. The parameters that will be changed for each servo are defined in the Table 1 at the beginning of this section.
12. Disconnect the power from the OpenRB-150 by unplugging the 5V/4A power supply from the barrel connector jack (female).
13. Connect a servomotor to the OpenRB-150 using the black cable with 3 wires that came in the box of the servo

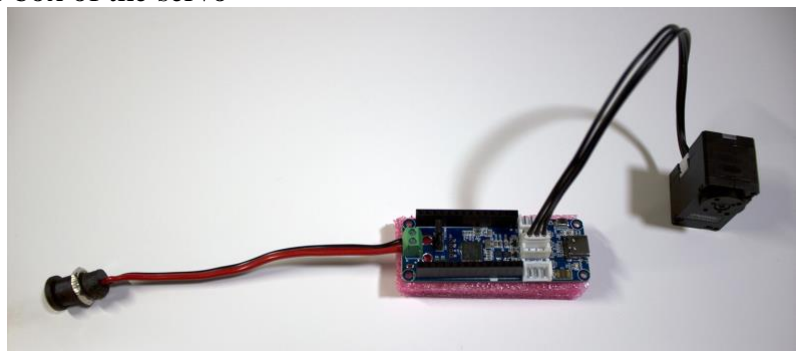
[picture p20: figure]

14. Reconnect the power as described in step 5.
15. Now click the “Scan” button in the Dynamizel Wizard 2.0 software. Once the servo that you connected shows up in the left pane you can click the “skip” button to stop scanning and move on to adjusting the parameters of the servo:
16. As mentioned previously you will need to adjust the parameters for each servo separately, but let’s setup the one for the Chopsticks gripper here as an example. Here are the default settings:

17. Change the ID to 5, baud rate to 3 (1 Mbps), and return delay time to 10 (20 usec), Min Position Limit to 1650, and Max Position Limit to 2658, and PWM Limit to 354. You will need to select the register to change the value and then click the ‘save’ button to make these changes.
a. NOTE1: It is very important to set the max and minimum position limits before you ever connect the servos to another software in order to prevent the servos, brackets, or cables from being damaged by moving beyond their range of motion. You can check the range of motion of a given joint or mechanism by manually moving the joint and reading out the max and min positions from the ‘present position’ register when the torque is turned off.
b. NOTE2: The PWM limits are also an effective way of helping prevent the arm from damaging itself or overloading by pushing too hard into the table or other obstacles. If you want to carry heavier payloads you can increase the elbow and wrist flexion servos to as high as 354 without them overloading, but we think these lower values should work well for most applications. After you change the value in the register it will not be active until you cycle the power on the servo.
c. NOTE3: Be very careful when setting the baud rate and ensure that you do not accidentally set it to higher than 1 Mbps as this will make it so that the actuator can no longer communicate with the OpenRB-150 and a separate U2D2 will be required to set the baud rate back to a lower value.
18. You can also try moving the servo in the Dynamixel Wizard 2.0 software
a. Set the “Profile Velocity” register (address 112) to a reasonably low testing speed such as 40 (9 RPM)

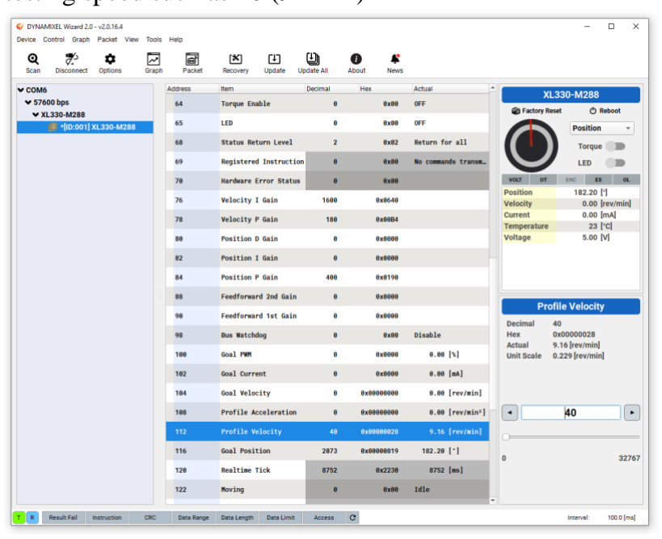
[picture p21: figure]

b. Set the “Torque Enable” register (address 64) to 1 to turn on torque to the motor.

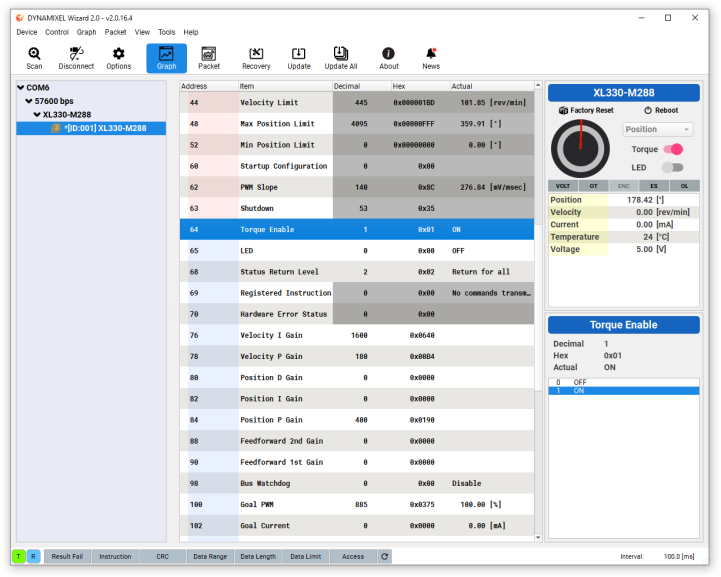
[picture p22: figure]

c. After clicking on the “Goal Position” register (address 116) you can then change the goal position using the rotational control that is built into the software. When you are done moving the servo please re-center it by setting the goal position to 0 degrees. This will ensure the servo horn is aligned properly for assembly. NOTE: It is very important to set the moving speed first otherwise the servo defaults to moving as fast as possible which will increase the chances of causing damage if the settings are incorrect.
19. Click the “Disconnect” button in the Dynamixel Wizard 2.0 software and then repeat steps 11 to 17 to program the next servo and set its parameters according to Table 1 until you have finished with all the servos.

### 1.5 Arm Assembly

Required Tools: #1 Drive Phillips Screwdriver (3.8mm diameter or less), needle nose pliers, wire cutters, wire strippers, soldering iron (optional)
Required Materials:
Estimated time: 1.5 hours

When going through each of the following steps it may help to open the 3D model in a 3D CAD program (Solidworks (https://github.com/BLINCdev/Mini-Bento/tree/main/Solidworks%20Files) or STEP) (https://github.com/BLINCdev/Mini-Bento/tree/main/Step%20Files) to find the names of parts and their orientations that they need to be assembled in.

1. To make the next assembly steps easier we recommend organizing the screws that came with the servomotors and brackets into 4 separate containers or bags. If you do not have any containers then you can organize them into the small ziplock bags that came with the XL-330 actuators.
a. M2x8mm TAP screws (black)
b. M2x6mm TAP screws (black)
c. M2x4mm TAP screws (black)
d. M2x4mm screws (silver) and M2 nuts (silver)
e. NOTE: Be careful to use the correct screw length and type for each step otherwise parts may be damaged. For example, if you use 8mm screws in the servo horns it may permanently damage the servo as seen in the following illustration:

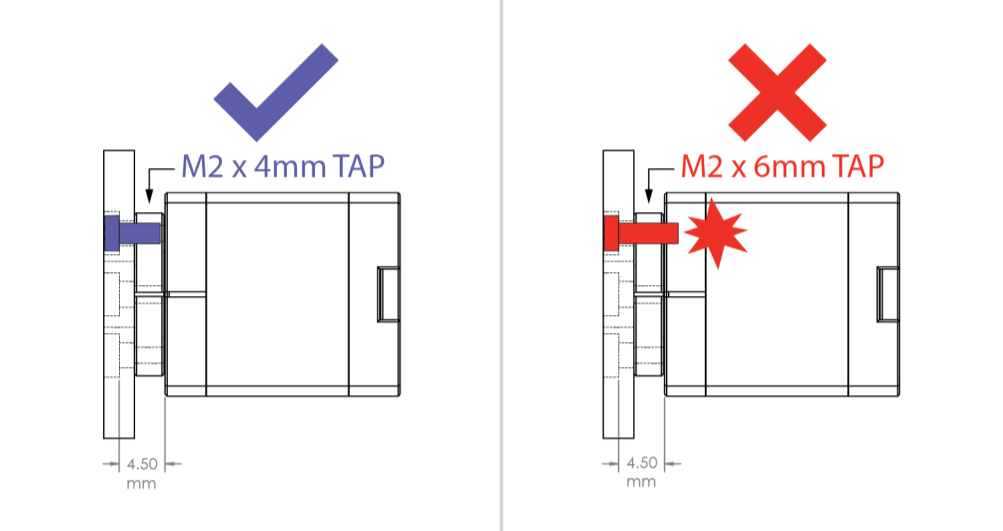
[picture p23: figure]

2. Carefully unscrew the hex nut from DC Barrel Jack (female). The plastic threads are very soft and prone to cross-threading. If the nut starts to bind back off and try again. If after a few tries you are not able to get the nut off without binding then the connector may have already have been cross-threaded at the factory. In that case you can use needle nose pliers to unscrew the hex nut.

3. Connect the DC Barrel Jack (female) to stand_base by feeding the wires through the hole in the outside of the stand. Once the connector is flush with the outside of the stand you can slide the hex nut onto the wires and into the hex shaped hole on the inside of the stand. You can then rotate the part of the connector on the inside of the stand to get the nut to tighten using needle nose pliers.

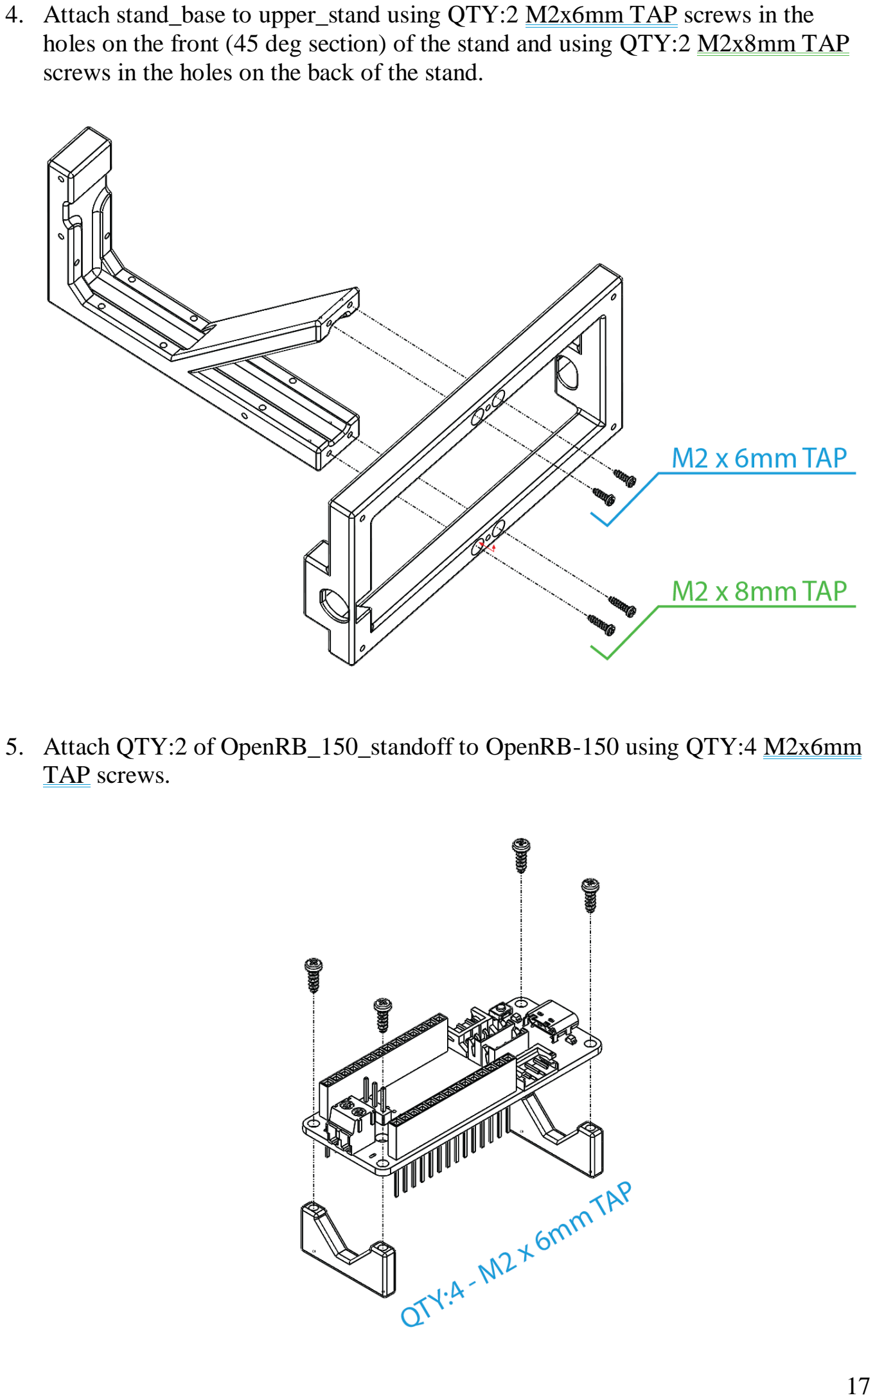
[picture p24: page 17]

4. Attach stand_base to upper_stand using QTY:2 M2x6mm TAP screws in the holes on the front (45 deg section) of the stand and using QTY:2 M2x8mm TAP screws in the holes on the back of the stand.
5. Attach QTY:2 of OpenRB_150_standoff to OpenRB-150 using QTY:4 M2x6mm TAP screws.

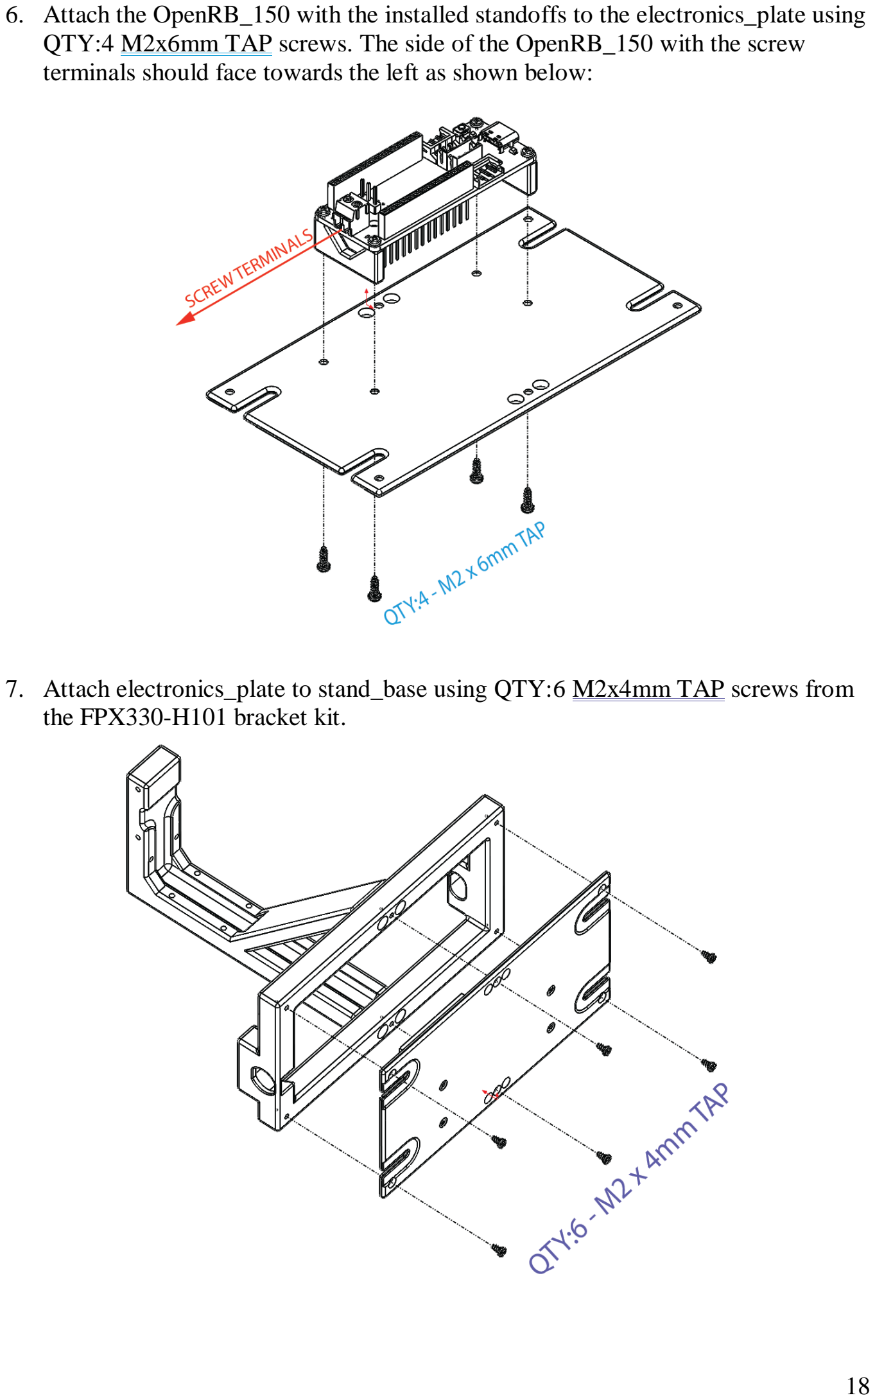
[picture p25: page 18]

6. Attach the OpenRB_150 with the installed standoffs to the electronics_plate using QTY:4 M2x6mm TAP screws. The side of the OpenRB_150 with the screw terminals should face towards the left as shown below:
7. Attach electronics_plate to stand_base using QTY:6 M2x4mm TAP screws from the FPX330-H101 bracket kit.

8. Attach QTY:2 corner brackets to stand assembly using QTY:4 M2x8mm TAP screws.
9. Attach the power wires from the DC Barrel Jack (female) to the OpenRB-150 making sure that the red wire goes into the side labelled “+” and the black wire goes into the side labelled “-“. The wires fit nicely into the base when wrapped between the OpenRB-150 and the upper stand and then back around the base to the wire terminals. Once the wires are in place, use a screw driver to tighten the terminal blocks until the wires are secure.

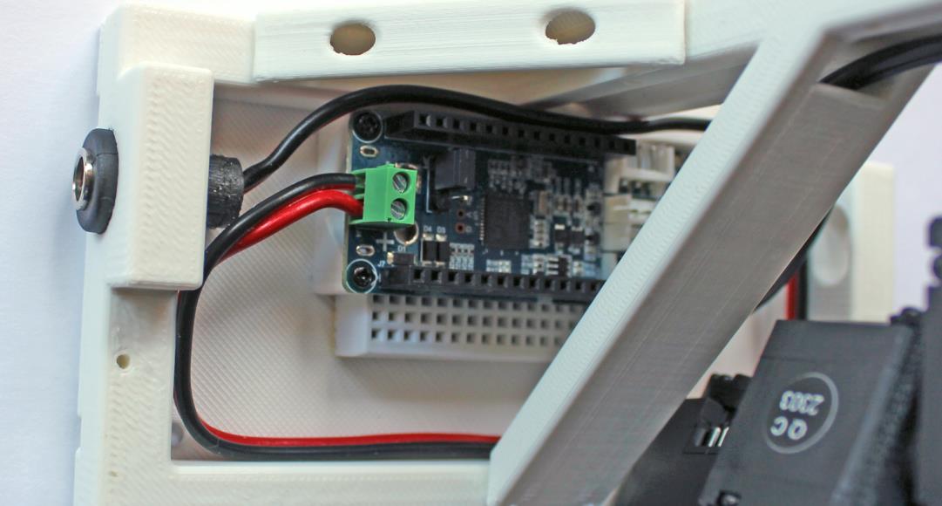
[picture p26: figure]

10. Attach XL-330_side_bracket to the shoulder actuator using QTY:4 M2x4mm TAP screws. Ensure that the notch on the servo horn aligns with the notch on the servo casing and that the bracket is also aligned as shown below:
11. Attach QTY:2 180mm cables to the shoulder actuator (XL330-M288-T, ID:1). Place the shoulder_adapter against the back of the actuator making sure that the right cable feeds through the slot in the bracket and the left cable folds over and goes out the side of the bracket (as shown below).

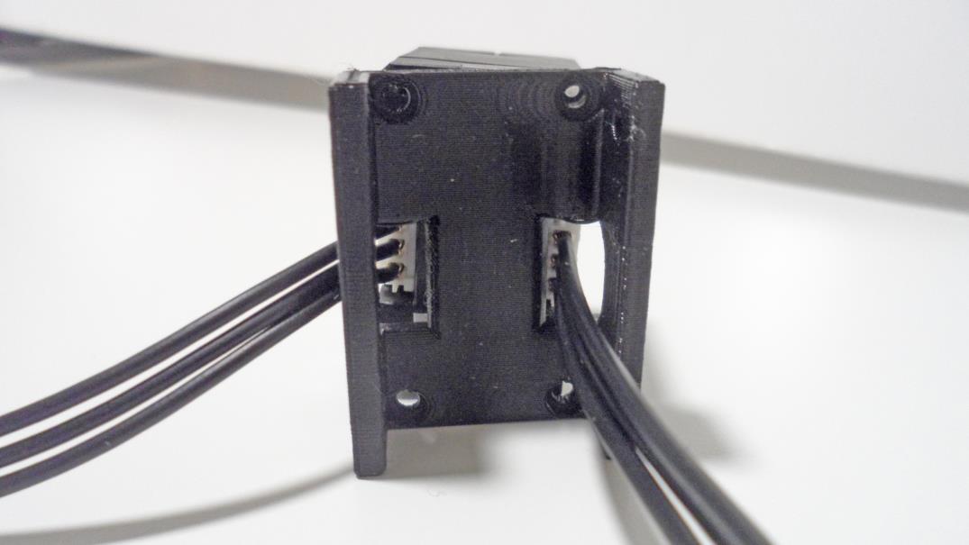
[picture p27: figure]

12. Attach shoulder_adapter to the shoulder actuator using QTY:4 M2x8mm TAP screws.
13. Carefully guide the cable on the right side (when viewing the stand from behind) into the cable channel of the upper_stand, so it lies flat and the cable on the left side folds down and out of the shoulder_adapter (see photo below).

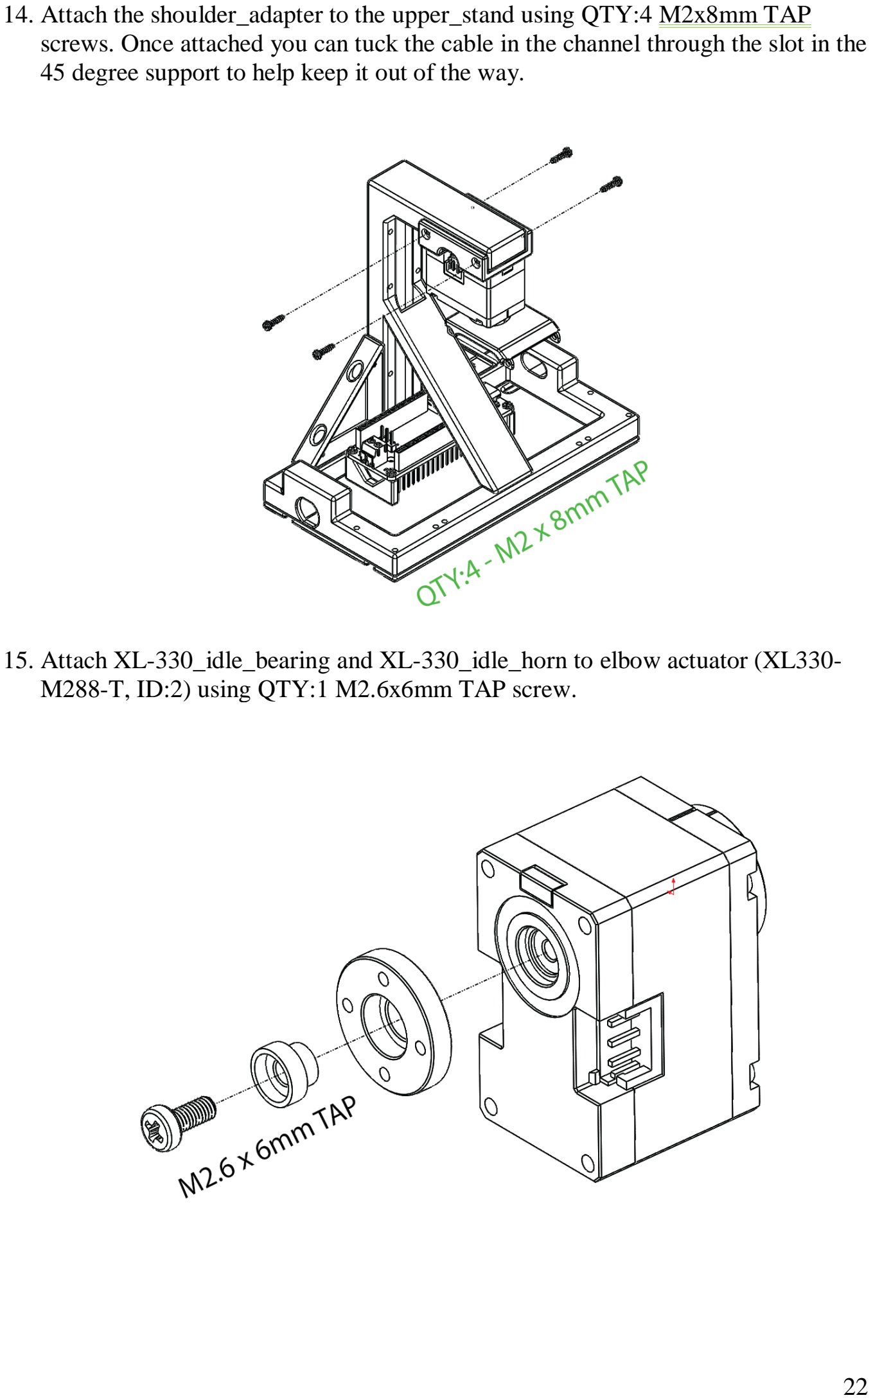
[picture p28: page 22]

14. Attach the shoulder_adapter to the upper_stand using QTY:4 M2x8mm TAP screws. Once attached you can tuck the cable in the channel through the slot in the 45 degree support to help keep it out of the way.
15. Attach XL-330_idle_bearing and XL-330_idle_horn to elbow actuator (XL330-M288-T, ID:2) using QTY:1 M2.6x6mm TAP screw.

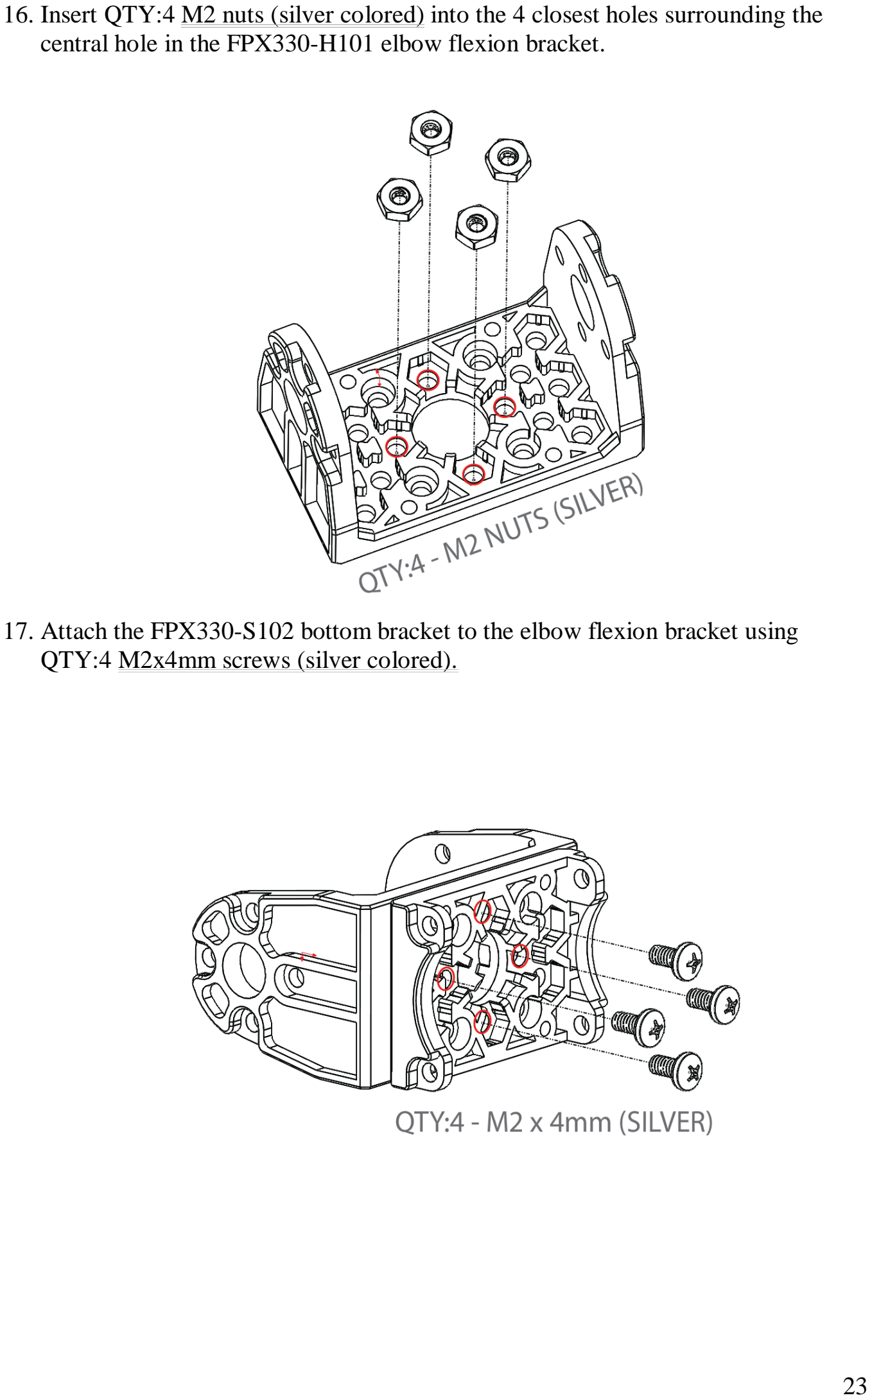
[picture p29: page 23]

16. Insert QTY:4 M2 nuts (silver colored) into the 4 closest holes surrounding the central hole in the FPX330-H101 elbow flexion bracket.
17. Attach the FPX330-S102 bottom bracket to the elbow flexion bracket using QTY:4 M2x4mm screws (silver colored).

18. Attach the elbow flexion bracket to the elbow actuator using QTY:8 M2x4mm TAP screws. Ensure that the notch on the servo horn aligns with the notch on the servo casing and that the bracket is also aligned as shown below:
19. Attach the elbow actuator to XL-330_side_bracket using QTY:4 M2x8mm TAP screws.

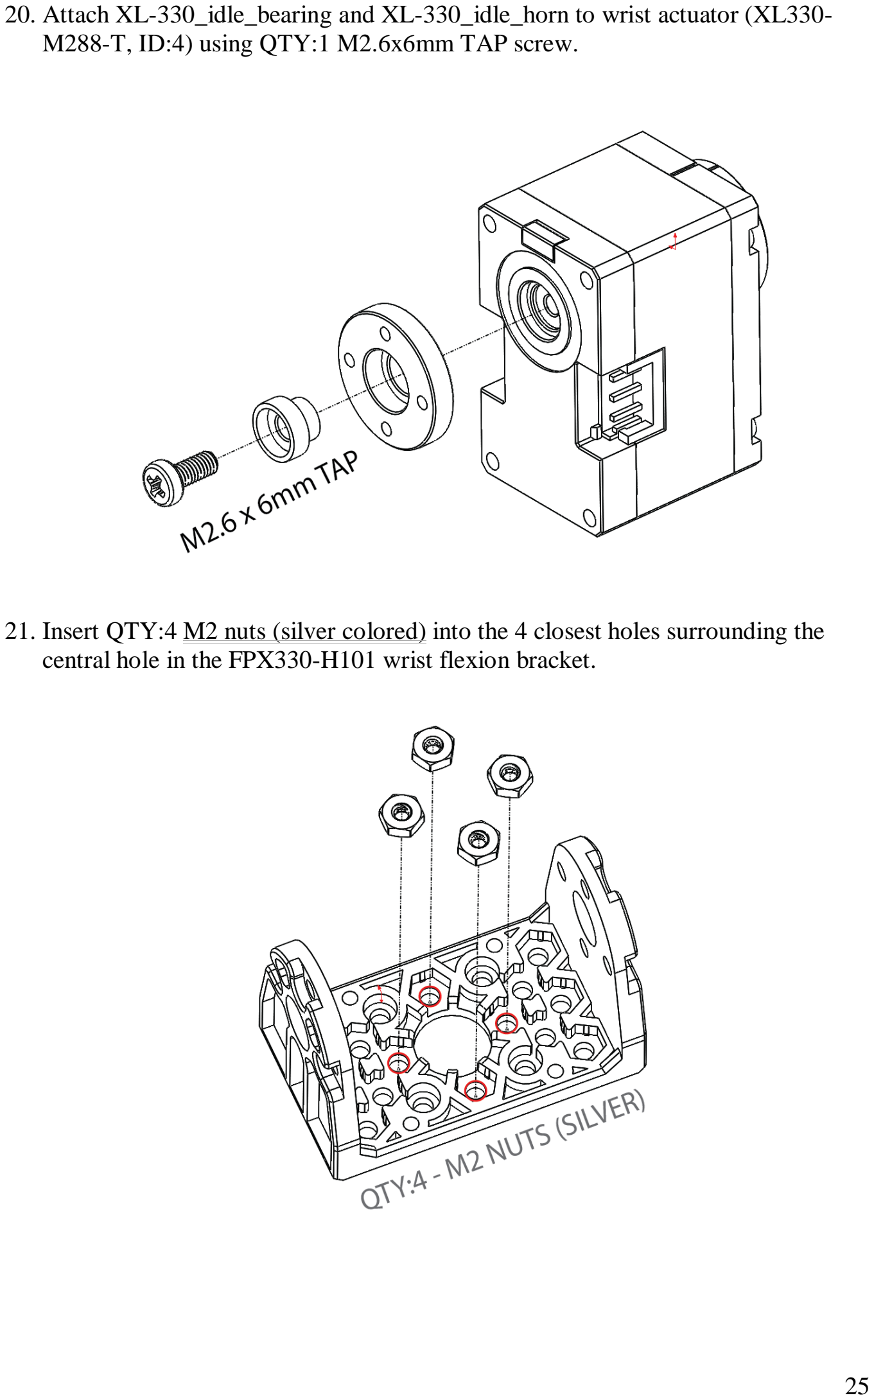
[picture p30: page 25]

20. Attach XL-330_idle_bearing and XL-330_idle_horn to wrist actuator (XL330-M288-T, ID:4) using QTY:1 M2.6x6mm TAP screw.
21. Insert QTY:4 M2 nuts (silver colored) into the 4 closest holes surrounding the central hole in the FPX330-H101 wrist flexion bracket.

22. Attach the FPX330-S102 bottom bracket to the wrist flexion bracket using QTY:4 M2x4mm screws (silver colored).
23. Attach the wrist flexion bracket to the wrist actuator using QTY:8 M2x4mm TAP screws. Ensure that the notch on the servo horn aligns with the notch on the servo casing and that the bracket is also aligned as shown below:

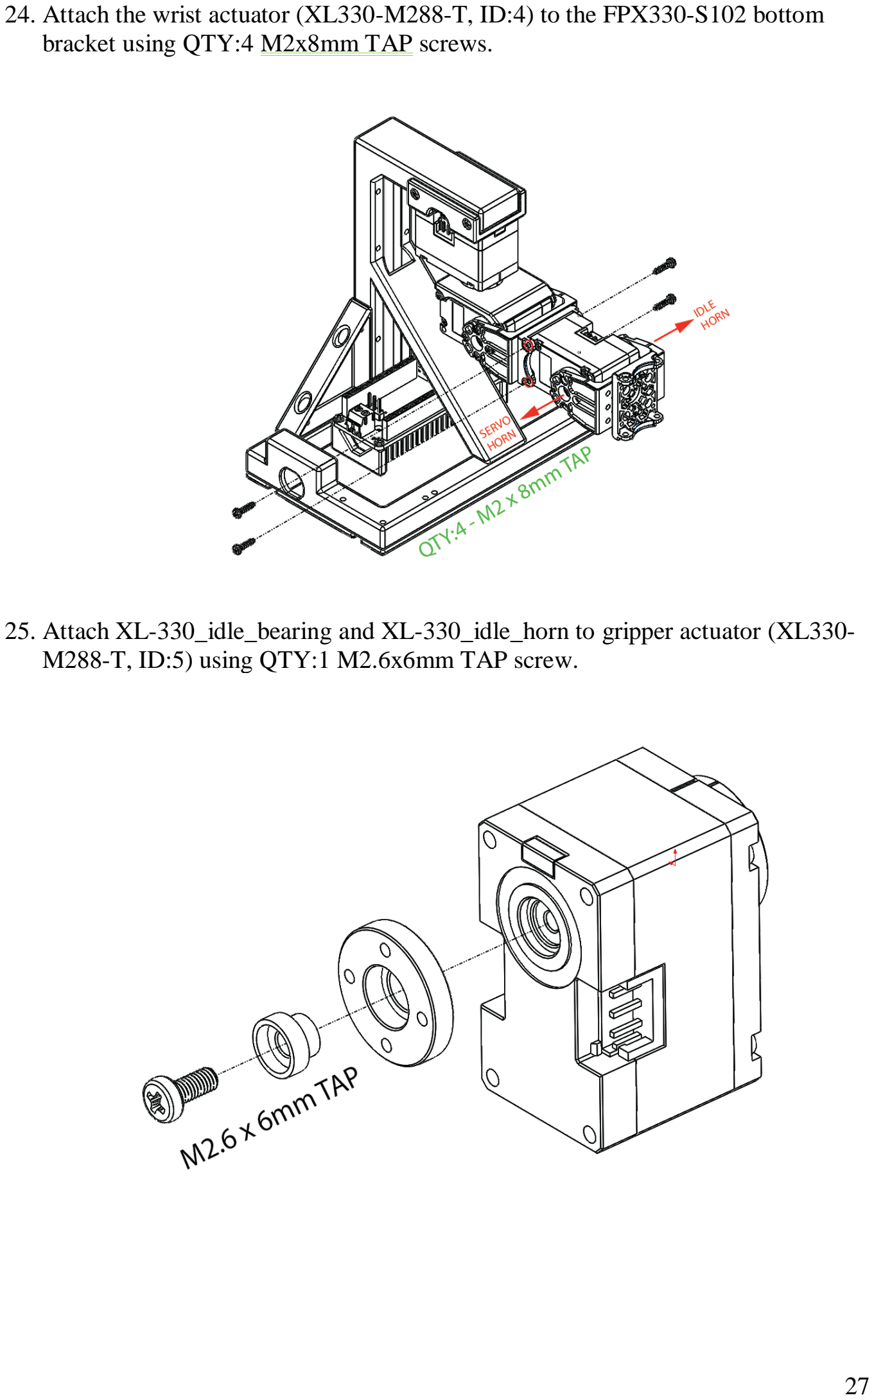
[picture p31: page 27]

24. Attach the wrist actuator (XL330-M288-T, ID:4) to the FPX330-S102 bottom bracket using QTY:4 M2x8mm TAP screws.
25. Attach XL-330_idle_bearing and XL-330_idle_horn to gripper actuator (XL330-M288-T, ID:5) using QTY:1 M2.6x6mm TAP screw.

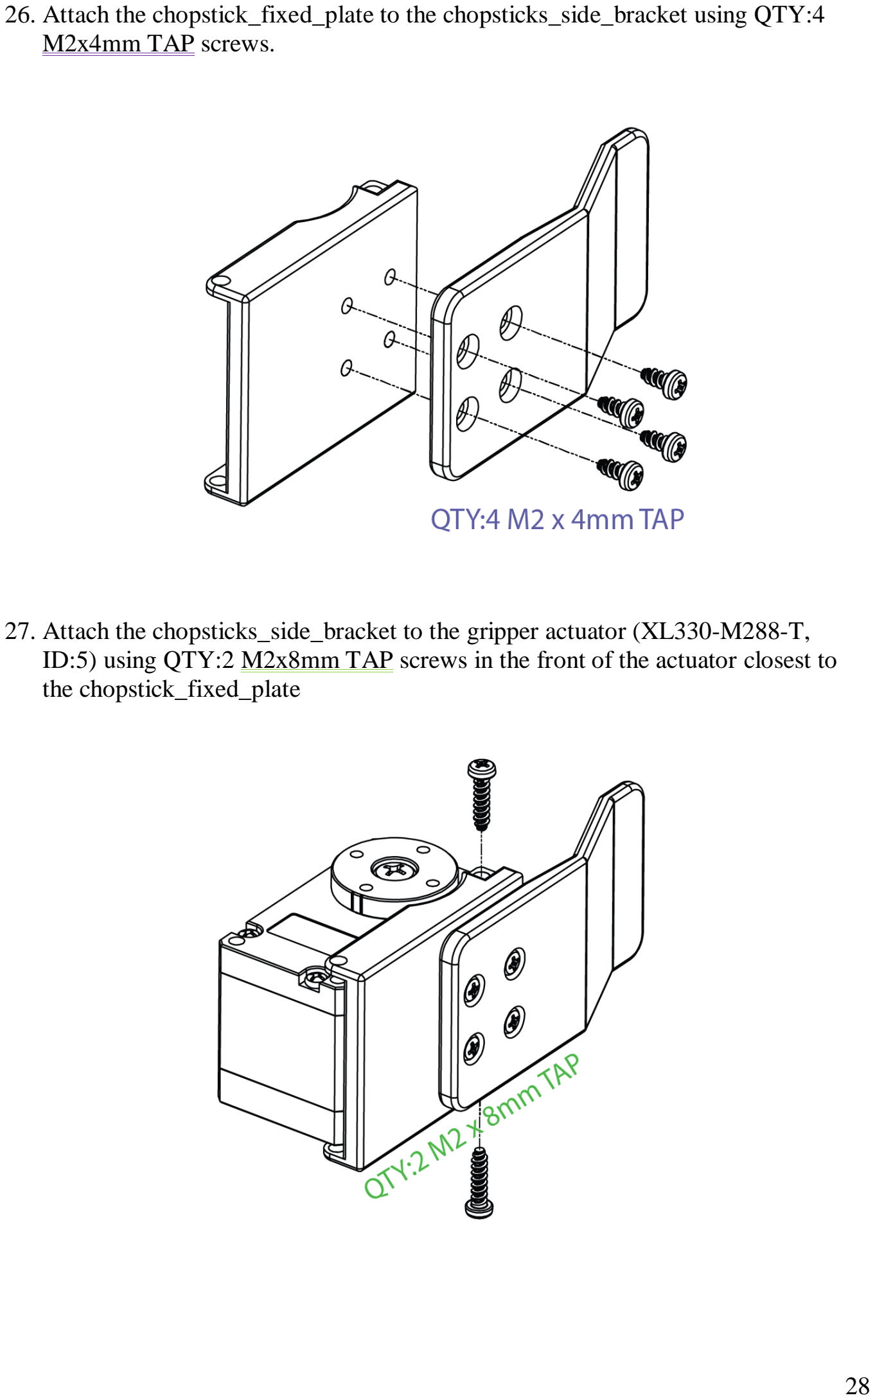
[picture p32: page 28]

26. Attach the chopstick_fixed_plate to the chopsticks_side_bracket using QTY:4 M2x4mm TAP screws.
27. Attach the chopsticks_side_bracket to the gripper actuator (XL330-M288-T, ID:5) using QTY:2 M2x8mm TAP screws in the front of the actuator closest to the chopstick_fixed_plate

28. Attach chopsticks_moving_plate to chopsticks_flex_bracket using QTY:4 M2x4mm TAP screws.
29. Attach chopsticks_flex_bracket to the hand actuator using QTY:8 M2x4mm TAP screws. Ensure that the notch on the servo horn aligns with the notch on the servo casing and that the bracket is also aligned as shown below:

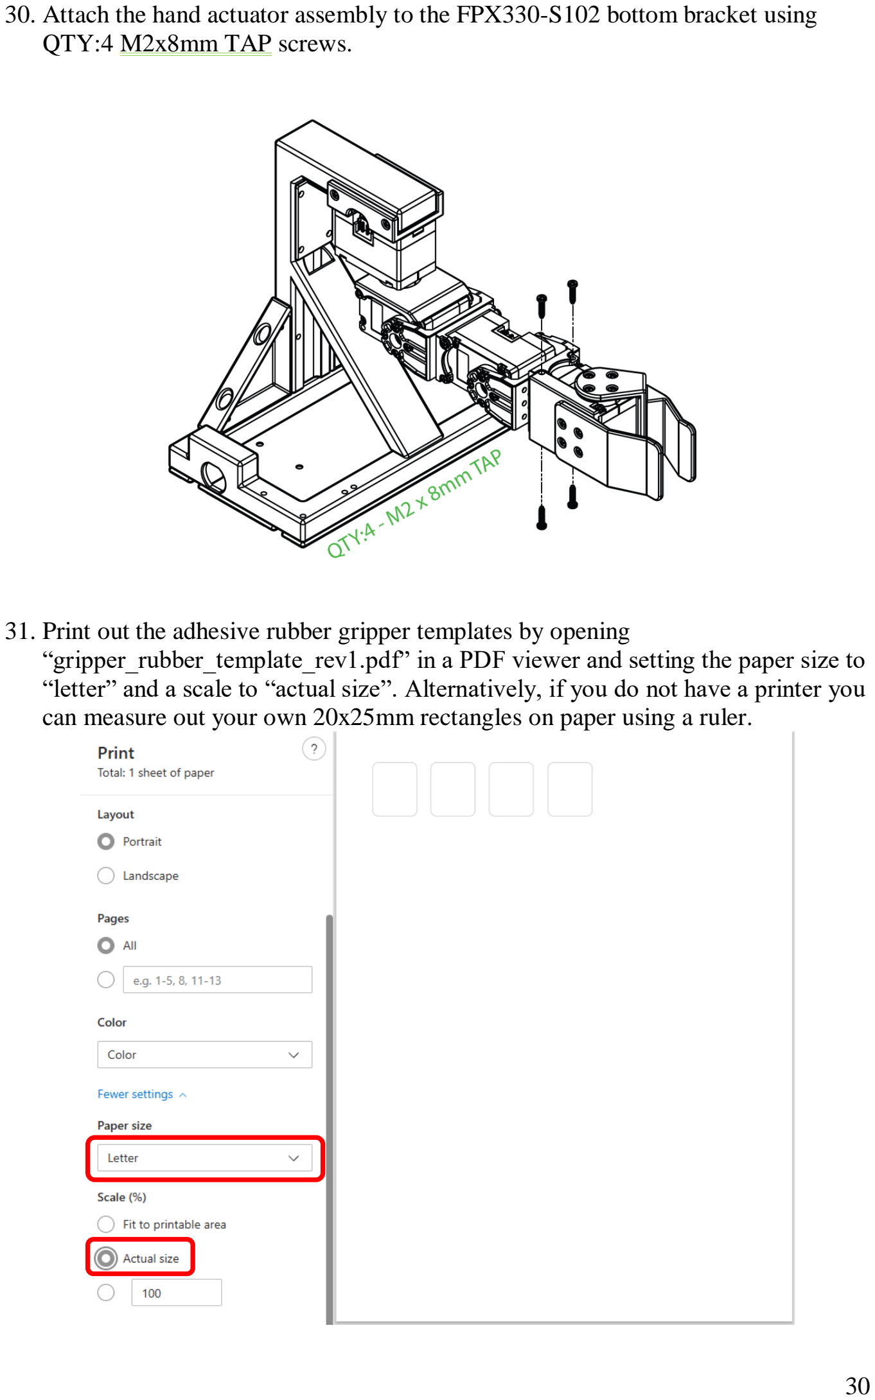
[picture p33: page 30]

30. Attach the hand actuator assembly to the FPX330-S102 bottom bracket using QTY:4 M2x8mm TAP screws.
31. Print out the adhesive rubber gripper templates by opening “gripper_rubber_template_rev1.pdf” in a PDF viewer and setting the paper size to “letter” and a scale to “actual size”. Alternatively, if you do not have a printer you can measure out your own 20x25mm rectangles on paper using a ruler.

32. Cut out the paper templates using scissors and then place the paper templates over the adhesive rubber and cut out QTY:2 rectangular grips. If you are just making one kit then we recommend cutting out the rubber using positions A, B, or C as seen below. If you are making multiple kits then you can get more grips out of a single kit by also using D, E, F, G, and H.
33. Apply the adhesive rubber grips to the Mini Bento Chopsticks gripper plates as seen in the following illustration. If you are using pieces from A, B, or C you can probably just place them by hand, but if you are using sections D, E, F, G, or H then we recommend using a transfer tape process (see video (https://www.youtube.com/watch?v=FEPOMmcK4i4) for more details) to avoid having to place all the small hexagons individually. We have found that transparent duct tape works well as a transfer tape with this rubber.

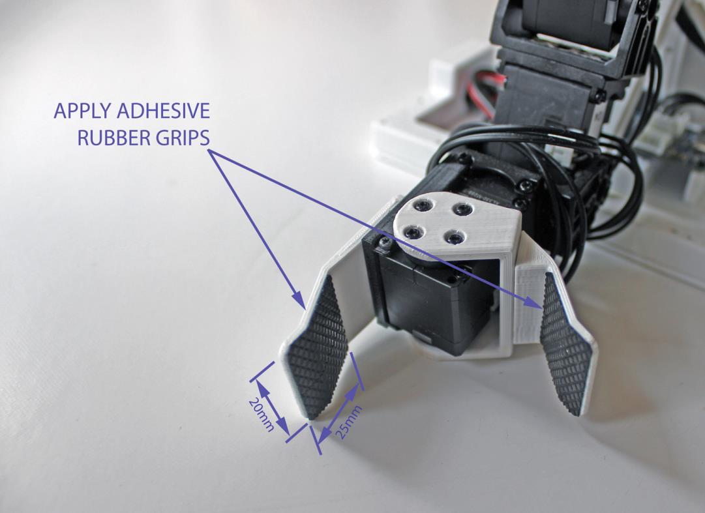
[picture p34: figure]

34. Connect the actuators together with the 180mm cables wrapping them around the servos as shown in the following image:
a. Attach a 180mm cable from the shoulder actuator (ID:1) to the elbow actuator (ID:2).
b. Attach a 180mm cable from the elbow actuator (ID:2) to the wrist actuator (ID:4)
c. Attach a 180mm cable from the wrist actuator (ID:4) to the gripper actuator (ID:5)

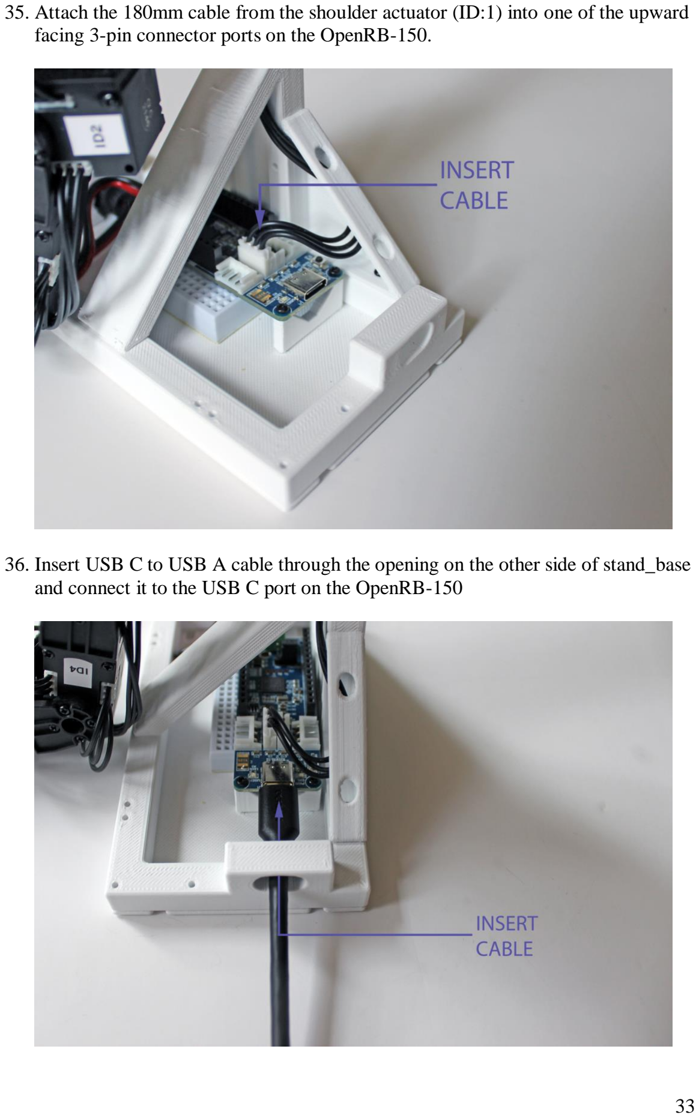
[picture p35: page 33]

35. Attach the 180mm cable from the shoulder actuator (ID:1) into one of the upward facing 3-pin connector ports on the OpenRB-150.
36. Insert USB C to USB A cable through the opening on the other side of stand_base and connect it to the USB C port on the OpenRB-150

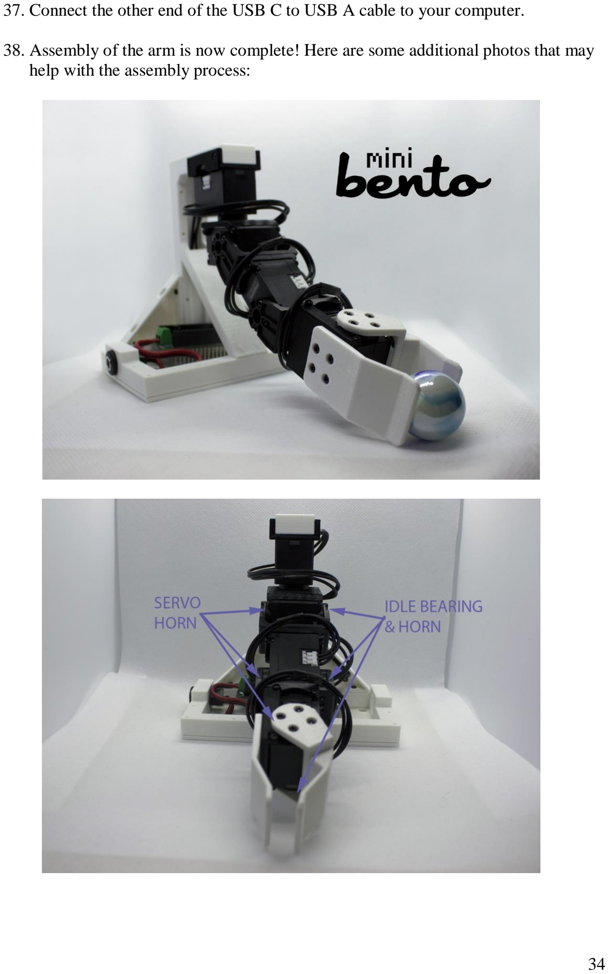
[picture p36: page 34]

37. Connect the other end of the USB C to USB A cable to your computer.
38. Assembly of the arm is now complete! Here are some additional photos that may help with the assembly process:

### 1.6 Optional Modifications

1. If the DC Barrel Jack (female) is still attached to the OpenRB-150 from the Dynamixel Servo programming, disconnect it by loosening the screw terminals using a screw driver and remove the wires.
2. Cut the wires on the DC Barrel Jack (female) to a length of 115mm using wire cutters. Separate the ends of wires, so that the separated length is about 15mm and then strip 5mm of insulation off the ends of each wire. Twist up the end of each wire to keep the strands together and then tin the ends of the wires using solder to help keep the strands together. If you do this step be sure to not add too much solder otherwise it may make it difficult to insert the wires into the terminals on the OpenRB-150.

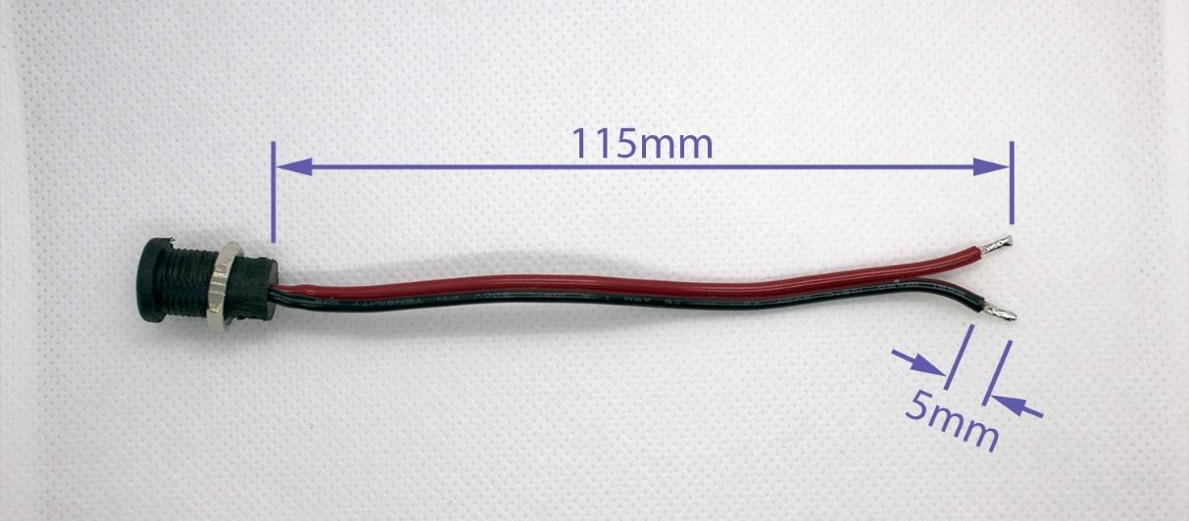
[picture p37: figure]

### 1.7 Arduino (Low Level Software)

Estimated Time: 30 minutes
Required Tools: Computer with Windows 10 or higher, OpenRB-150 (https://emanual.robotis.com/docs/en/parts/controller/openrb-150/) or similar, 5V/4A power supply, DC Barrel Jack (female), USB C to USB A cable
1. Attach QTY:1 thumb joystick to the left side (when viewed from behind) of the stand_base using QTY:3 M2x8mm TAP screws. Ensure the header pins point towards the OpenRB-150.
2. With the power supply and USB cable unplugged, connect the prototyping wires between the thumb joystick and OpenRB-150 according to the following wiring diagram:

NOTE: It is possible to plug in the wires with everything assembled, but you can also temporarily remove the screws from the electronics plate and stand base or from the upper stand to make it easier before reassembling.

20. Power on the OpenRB-150 by plugging the 5V/4A power supply into a surge protector or wall outlet and connecting the barrel plug (male) of the power supply to the DC Barrel Jack (female). The green LED on the OpenRB-150 should illuminate indicating that the board has power. A few seconds later the red LED on the OpenRB-150 should also turn on indicating that the Dynamixel bus has initialized and is also now sending power to any connected Dynamixel servos.
21. Connect the OpenRB-150 to the computer using the USB C to USB A cable. If this is the first time you have connected the device Windows may give some notifications that a new device is being setup.
22. Download mini_bento_joint_velocity_control_rev2 (https://github.com/BLINCdev/Mini-Bento/blob/main/Arduino/mini_bento_joint_velocity_control_rev2/mini_bento_joint_velocity_control_rev2.ino) sketch and extract it to a folder on your computer.

23. Open the “mini_bento_joint_velocity_control_rev2” sketch and upload it in the in the Arduino IDE
a. Go “tools > board > OpenRB-150” and select “OpenRB-150”
b. Go “tools > port” and select the option that has “(OpenRB-150)” next to it.
c. Click “upload” in the “mini_bento_joint_velocity_control_rev2” sketch to upload the sketch to the OpenRB-150
24. The sketch will take a few seconds to upload and then you can control a single joint on the Mini Bento at a time by moving one of the axes on the joystick. Click the thumb joystick to switch sequentially through the joints (the LED of the selected actuator will glow red)

### 1.8 brachI/Oplexus (High Level Software)

Estimated Time: 30 min
Required Tools: Computer with Windows 10 or higher, OpenRB-150 (https://emanual.robotis.com/docs/en/parts/controller/openrb-150/) or similar, 5V/4A power supply, DC Barrel Jack (female), USB C to USB A cable
NOTE: Support for the Mini Bento Arm in brachI/Oplexus is in beta. If you would like to try it out please contact us and we can send you early access to the project files.
1. Download the “usb_to_dynamixel” (https://github.com/ROBOTIS-GIT/OpenRB-150/blob/master/libraries/OpenRB-150/examples/usb_to_dynamixel/usb_to_dynamixel.ino) sketch and extract it to a folder on your computer.
2. Open the “usb_to_dynamixel” sketch and upload it in the in the Arduino IDE
a. Go “tools > board > OpenRB-150” and select “OpenRB-150”
b. Go “tools > port” and select the option that has “(OpenRB-150)” next to it.
c. Go “file > examples > OpenRB-150” and select the “usb_to_dynamixel” sketch. A new window should open in the Arduino IDE that is titled “usb_to_dynamixel”
d. Click “upload” in the “usb_to_dynamixel” sketch to upload the sketch to the OpenRB-150
3. If you haven’t already as part of installing the Dynamixel Wizard 2.0, download and install the Microsoft Visual C++ 2015-2019 Redistributable (x86) from the following link:

https://www.dropbox.com/s/3e5horhq73hm677/VC_redist.x86.exe?dl=0

a. If the redistributable is already installed on your computer then you don’t need to reinstall it. You can check to see if it is installed by searching for “add or remove programs” and then looking to see if “Microsoft Visual C++ 2015-2019 Redistributable (x86) is present.

4. Contact us (https://blincdev.ca/contact/) to request the special version of the brachI/Oplexus software that works with the Mini Bento Arm and extract it to a folder on your desktop.
5. Navigate to the path with the executable:

GUI_DOF6_12ch_BENTO_rev52b_dyna2b\Example1\bin\x86\Debug

6. Click on “brachIOplexus.exe” to run brachI/Oplexus
a. You can also right click on the executable and select “create shortcut” and then drag onto your desktop for easy access
7. Once brachI/Oplexus opens you can try out the Virtual Bento Arm by clicking the “Launch Virtual Bento Demo” in the “Input/Output” tab
a. Here is the mapping to control the Virtual Bento Arm with the keyboard

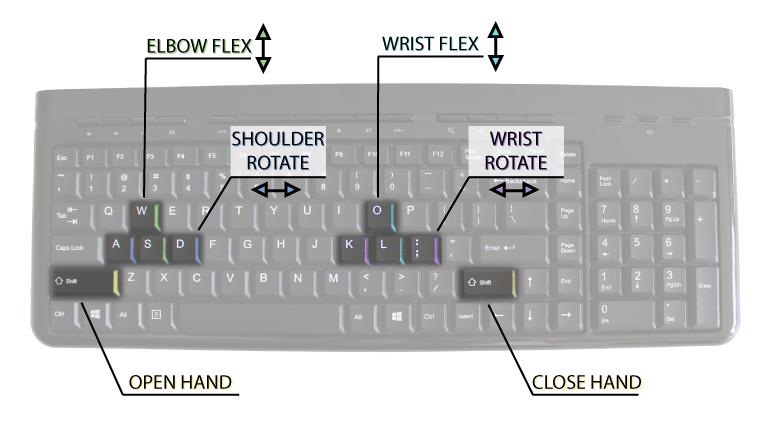
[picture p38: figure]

8. Once you have finished trying the Virtual Bento Arm you can close the unity window and go back to the input/output tab and click “connect” in the “Bento Arm – Setup” groupbox
9. Now you can try controlling your Mini Bento Arm with the keyboard by navigating to the “Bento Arm” tab in brachI/Oplexus and clicking “Torque On” and “Run”

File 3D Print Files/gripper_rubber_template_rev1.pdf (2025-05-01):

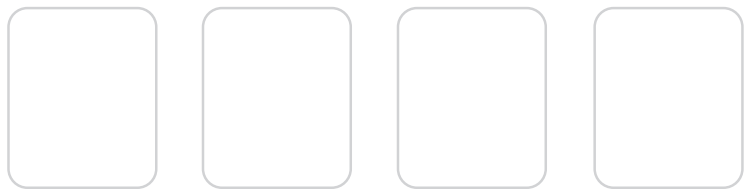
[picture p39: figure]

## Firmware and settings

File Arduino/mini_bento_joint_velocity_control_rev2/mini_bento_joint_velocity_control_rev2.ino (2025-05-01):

// Mini Bento Arm / PS2 Thumb Joystick - Joint Velocity Controller
// Version 0.1
// Author: Michael (Rory) Dawson
//
// Objective: This sketch provides sequential joint velocity control of Mini Bento Arm using a PS2 Thumb Joystick. 
// The vertical axis on the thumb joystick is used to proportionally control the velocity of the selected joint
// and the tactile button when you push down the thumb joystick is used to sequentially switch between the joints.
// The QTY:4 XL330-M288-T are pre-configured in the Dynamixel Wizard 2.0 software to be in position mode with CW/CCW joint
// limits as defined in the setup() section. This example code has been tested and verified to work with the OpenRB-150.
// 
// Definitions:
// ID1: shoulder rotate
// ID2: elbow flex
// ID3: wrist rotate (not available on the Mini Bento Arm)
// ID4: wrist flex
// ID5: hand open/close
//
// PS2 Thumb Joystick Pinout:
// GND: Connect to GND on OpenRB-150
// +5V: Connect to 3.3V (VCC) pin on OpenRB-150
// VRX: not connected in this sketch
// VRY: Connect to A0 pin on OpenRB-150
// SW: Connect to digital pin 5 on OpenRB-150
//
// Dynamixel Connections:
// Connect XL330-M288-T or similar to TTL port on OpenRB-150
// Connect 5V/4A PSU to power port OpenRB-150
//
// References:
// Structs: http://playground.arduino.cc/Code/Struct
// OpenRB-150: https://emanual.robotis.com/docs/en/parts/controller/openrb-150/

#include <DynamixelShield.h>

#if defined(ARDUINO_AVR_UNO) || defined(ARDUINO_AVR_MEGA2560)
  #include <SoftwareSerial.h>
  SoftwareSerial soft_serial(7, 8); // DYNAMIXELShield UART RX/TX
  #define DEBUG_SERIAL soft_serial
#elif defined(ARDUINO_SAM_DUE) || defined(ARDUINO_SAM_ZERO)
  #define DEBUG_SERIAL SerialUSB    
#else
  #define DEBUG_SERIAL Serial
#endif

const float DXL_PROTOCOL_VERSION = 2.0;
const int BENTO_NUM = 5;

DynamixelShield dxl;

//This namespace is required to use Control table item names
using namespace ControlTableItem;

// Define global array of structs to hold the parameters for each digit
struct motorParam {
  int enabled;             // 0 = disabled (not connected), 1 = enabled (connected)
  int CW_limit;            // the CW position limit for the servo (varies from 0-4095)
  int CCW_limit;           // the CCW position limit for the servo (varies from 0-4095)
  int min_vel;             // the minimum velocity (varies from 0-1023)
  int max_vel;             // the maximum velocity (varies from 0-1023)
  int state;               // 0 = stopped, 1 = moving CW, 2 = moving CCW
  int pos;                 // the current target position
  int pos_;                // the present position (feedback from servo)
  int vel;                 // the current target velocity
  int vel_;                // the present velocity (feedback from servo)
} motor[BENTO_NUM+1];

// Assign joystick axis and buttons to pins on the arduino
// Also connect the joystick VCC to Arduino 5V, and joystick GND to Arduino GND.

const int VERT = A0; // analog
const int HORIZ = A1; // analog
const int SEL =  5; // digital
int prev_state = 1;
int servoID = 1;
int chA_deadband = 20;  
int chA_neutral = 512;
int chB_deadband = 20; 
int chB_neutral = 512;

// This sketch outputs serial data at 115200 baud (open Serial Monitor to view).

void setup()
{
  // make the SEL line an input
  pinMode(SEL,INPUT_PULLUP);
  
  // Define shoulder rotate paramaters (X-series)
  motor[1].enabled = 0;       // disabled by default unless detected via pin command
  motor[1].CW_limit = 1500;       // the CW position limit for the servo
  motor[1].CCW_limit = 3073;   // the CCW position limit for the servo
  motor[1].min_vel = 1;           // the minimum velocity
  motor[1].max_vel = 50;         // the maximum velocity
  motor[1].pos = 2047;            // the current target position
  motor[1].vel = 10;           // the current target velocity

  // Define elbow extension paramaters (X-series)
  motor[2].enabled = 0;       // disabled by default unless detected via pin command
  motor[2].CW_limit = 1730;       // the CW position limit for the servo
  motor[2].CCW_limit = 2700;   // the CCW position limit for the servo
  motor[2].min_vel = 1;           // the minimum velocity
  motor[2].max_vel = 50;         // the maximum velocity
  motor[2].pos = 2047;            // the current target position
  motor[2].vel = 10;           // the current target velocity

  // Define wrist rotation paramaters (X-series)
  motor[3].enabled = 0;       // disabled by default unless detected via pin command
  motor[3].CW_limit = 1028;       // the CW position limit for the servo
  motor[3].CCW_limit = 3073;   // the CCW position limit for the servo
  motor[3].min_vel = 1;           // the minimum velocity
  motor[3].max_vel = 60;         // the maximum velocity
  motor[3].pos = 2047;            // the current target position
  motor[3].vel = 10;           // the current target velocity

  // Define wrist flexion paramaters (X-series)
  motor[4].enabled = 0;       // disabled by default unless detected via pin command
  motor[4].CW_limit = 848;       // the CW position limit for the servo
  motor[4].CCW_limit = 3248;   // the CCW position limit for the servo
  motor[4].min_vel = 1;           // the minimum velocity
  motor[4].max_vel = 60;         // the maximum velocity
  motor[4].pos = 2047;            // the current target position
  motor[4].vel = 10;           // the current target velocity

  // Define hand close/open paramaters (X-series)
  motor[5].enabled = 0;       // disabled by default unless detected via pin command
  motor[5].CW_limit = 1650;       // the CW position limit for the servo
  motor[5].CCW_limit = 2658;   // the CCW position limit for the servo
  motor[5].min_vel = 1;           // the minimum velocity
  motor[5].max_vel = 60;         // the maximum velocity
  motor[5].pos = 2047;            // the current target position
  motor[5].vel = 10;           // the current target velocity

 
  // For Uno, Nano, Mini, and Mega, use UART port of DYNAMIXEL Shield to debug.
  DEBUG_SERIAL.begin(115200);

  // Set Port baudrate to 1000000 bps. This has to match with DYNAMIXEL baudrate.
  dxl.begin(1000000);
  
  // Set Port Protocol Version. This has to match with DYNAMIXEL protocol version.
  dxl.setPortProtocolVersion(DXL_PROTOCOL_VERSION);


  // Get DYNAMIXEL information and initialize the connected servos
  delay(100);  // Add delay so there is time for the bus to initialize before starting to ping servos
  for(int i=1; i<=BENTO_NUM; i++)
  {
    motor[i].enabled = dxl.ping(i);
    dxl.torqueOff(i);   // Turn off torque when configuring items in EEPROM area
    dxl.setOperatingMode(i, OP_POSITION);  // Set operating mode to position control mode
    dxl.torqueOn(i);    // Turn the torque back on
    // Read the latest position and velocity values from the servo
    motor[i].pos_ = dxl.getPresentPosition(i);
    motor[i].vel_ = dxl.getPresentVelocity(i);
    StopVelocity(i);    // Set the initial positions equal to the current positions to ensure each servo is stopped
  }
  dxl.ledOn(servoID);   // Set the LED of the initially selected servo in the sequential switching list
}

void loop() 
{
  // read values from the external potentiometer
  int potValue = analogRead(VERT); // will be 0-1023
  int select = digitalRead(SEL); // will be HIGH (1) if not pressed, and LOW (0) if pressed

  // Read the latest position and velocity values from the servo
  motor[servoID].pos_ = dxl.getPresentPosition(servoID);
  motor[servoID].vel_ = dxl.getPresentVelocity(servoID);

  // Check for a switching event. If detected then switch to the next item in the sequential
  // switching list.
  if (select == LOW && prev_state == HIGH)
  {
    // If the active servo is moving then stop it
    if (motor[servoID].state != 0)
    {
      StopVelocity(servoID);
    }
    dxl.ledOff(servoID);  // turn off the LED of the old active joint
    servoID = servoID + 1;
    while (motor[servoID].enabled == 0) // Skip servos that are not connected
    {
      servoID = servoID + 1;
    }

    // Reset back to the first servo when exceed the number of servos in the arm
    if (servoID > BENTO_NUM)
    {
     servoID = 1;
    }
    dxl.ledOn(servoID);   // turn on the LED of the new active joint 
  }
  
  // Update the switch state
  prev_state = select;

  // Map the value of the external potentiometer to the goal position and velocity of the servo.
  // If outside of deadband and above neutral then move CCW
  if (potValue < chA_neutral - chA_deadband)
  {
    motor[servoID].pos = motor[servoID].CCW_limit;
    motor[servoID].vel = map(potValue, chA_neutral - chA_deadband, 0, motor[servoID].min_vel, motor[servoID].max_vel);
    dxl.setGoalPosition(servoID, motor[servoID].pos);
    dxl.writeControlTableItem(PROFILE_VELOCITY, servoID, motor[servoID].vel);
    motor[servoID].state = 2;  
  }
  // If outside of deadband and below neutral then move CW
  else if (potValue >= chA_neutral + chA_deadband)
  {
    motor[servoID].pos = motor[servoID].CW_limit;
    motor[servoID].vel = map(potValue-(chA_neutral+chA_deadband), 0, chA_neutral - chA_deadband, motor[servoID].min_vel, motor[servoID].max_vel);
    //motor[servoID].vel = 50;
    dxl.setGoalPosition(servoID, motor[servoID].pos);
    dxl.writeControlTableItem(PROFILE_VELOCITY, servoID, motor[servoID].vel);
    motor[servoID].state = 1;  
  }
  // Stop the servo if it is inside the deadband range and was previously moving. 
  // You should only stop the servo this way once otherwise it can cause the servo to sag down from gravity if done repeatedly
  else if (motor[servoID].state > 0)
  {
    StopVelocity(servoID);
    motor[servoID].state = 0;     
  }
 
  // Output sensor and motor feedback to the serial monitor
  DEBUG_SERIAL.print("Potentiometer Value: ");
  DEBUG_SERIAL.print(potValue);
  DEBUG_SERIAL.print(" Select Value: ");
  if(select == HIGH)
    DEBUG_SERIAL.print("not pressed");
  else
    DEBUG_SERIAL.print("PRESSED!");
  DEBUG_SERIAL.print(", servoID: ");
  DEBUG_SERIAL.print(servoID);
  DEBUG_SERIAL.print(", Present Position: ");
  DEBUG_SERIAL.print(motor[servoID].pos_);
  DEBUG_SERIAL.print(", Target Velocity: ");
  DEBUG_SERIAL.print(motor[servoID].vel);
  DEBUG_SERIAL.print(", Present Velocity: ");
  DEBUG_SERIAL.println(motor[servoID].vel_);
}  

// Stop the active servo by setting its target position equal to its current position
void StopVelocity(int j)
{
  // Offset by the value of the velocity to avoid jump back from feedback delay
  if (motor[j].pos == motor[j].CW_limit)
  {
    motor[j].pos = motor[j].pos_ + motor[j].vel_;
  }
  else if (motor[j].pos == motor[j].CCW_limit)
  {
    motor[j].pos = motor[j].pos_ + motor[j].vel_;
  }
  else
  {
    motor[j].pos = motor[j].pos_; // Set target position equal to the present position
  }
  motor[j].vel = motor[j].max_vel;
  dxl.setGoalPosition(j, motor[j].pos);
  dxl.writeControlTableItem(PROFILE_VELOCITY, j, motor[j].vel);
}

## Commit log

2025-05-01 Initial commit
    Includes the 3D files, assembly guide, print guide, bill of materials, and arduino code.
    [MIni Bento_Arm - 3D Printing Guide.xlsx, Mini Bento Arm - Bill of Materials.xls, OpenRB_150_simplified.SLDPRT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]
2025-05-01 Fixed some missing files, links, and typos
    Also added in the license for the arduino code and the paper template for applying the adhesive rubber to the chopsticks gripper.
